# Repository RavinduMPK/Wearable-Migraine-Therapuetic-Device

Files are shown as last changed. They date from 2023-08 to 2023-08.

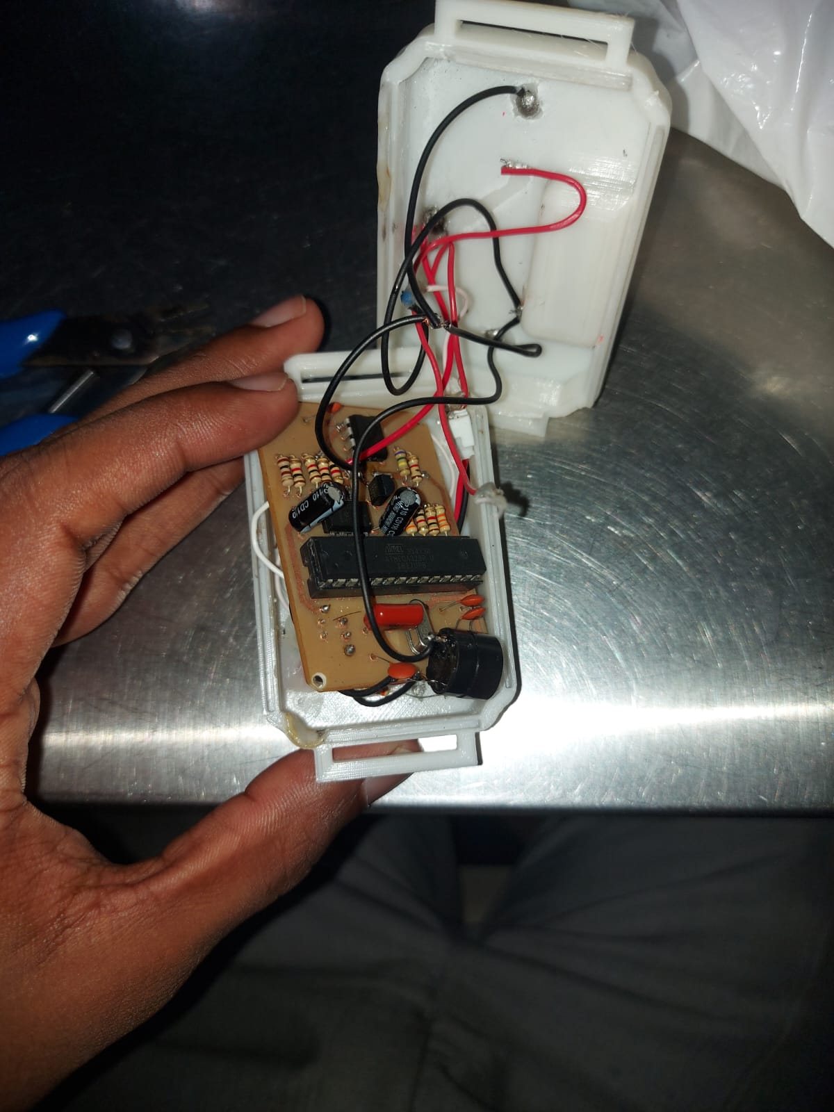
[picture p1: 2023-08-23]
Images/Internal.jpg

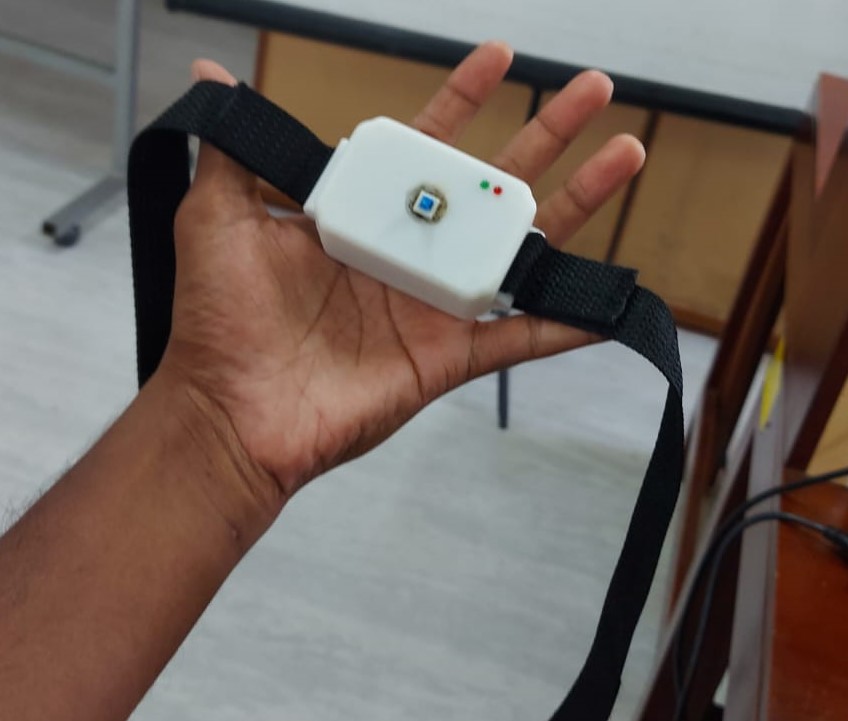
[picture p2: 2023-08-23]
Images/Device view.jpg

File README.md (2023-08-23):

# Wearable Migraine Therapeutic Device
Wear

## Problem

Migraine is a pressing global health issue that lacks a definitive solution. Research surveys have revealed that one out of every ten individuals worldwide experiences the debilitating effects of migraines. This intricate neurological condition manifests with the following characteristics:

- Intense headache localized to one side of the head.
- Moderate to severe throbbing sensation that worsens with movement.


While no permanent medical cure for migraines currently exists, certain methods can alleviate the pain to some extent. Many migraine sufferers resort to massaging their forehead as an external remedy, while others rely on painkillers as a medical treatment. However, these approaches come with limitations:

- Massaging requires interruption of daily activities and is time-consuming.
- Frequent use of painkillers can lead to side effects such as gastritis, ulcers, kidney or liver damage, and more.
These challenges are particularly problematic for students and busy individuals. Given these circumstances, there exists a critical demand for a viable and effective solution to address the issues posed by migraines.

Migraine affects 1 in 10 people globally, causing intense headaches and disruptions. Conventional treatments like painkillers are either time-consuming or carry side effects. An effective and non-invasive solution is needed.


## Solution

Introducing the Wearable Migraine Therapeutic Device – a user-friendly solution that utilizes nerve stimulation to reduce migraine pain. The device offers on-the-go relief, allowing users to continue their activities without interruption.
Device view

### Transcutaneous Electrical Nerve Stimulation (TENS)
Transcutaneous Electrical Nerve Stimulation (TENS) has emerged as a popular non-invasive and self-administered technique for pain relief. This method involves the delivery of a minuscule electrical current through the skin using electrode pads attached to the skin surface. A significant advantage of TENS is its minimal side effects.

The underlying mechanism of TENS is based on the gate control theory of pain. This method effectively reduces the transmission of pain sensation messages to the brain by deactivating relevant sensory fibers. Our approach focuses on alleviating migraine pain by strategically placing electrodes on the forehead. We specifically target the afferent paths of the Supratrochlear and Supraorbital nerves, which belong to the ophthalmic branch of the Trigeminal nerve.

Our method employs high-frequency, low-intensity electrical signals. We begin with low intensity and gradually increase it. This approach is designed to stimulate large diameter, low threshold fibers (A-beta) initially, followed by high threshold fibers (A-delta). This sequential stimulation pattern effectively reduces the transmission of migraine pain sensation messages to the brain, providing relief to patients during migraine episodes.

## Key Features

- **Nerve Stimulation:** Utilizes nerve stimulation to alleviate migraine pain effectively.
- **User-friendly Design:** Lightweight and comfortable for extended wear.
- **Safe and Low Power:** Designed with safety and low power consumption in mind.
- **Gradual Relief:** Provides gradual pain relief during operation.
- **Adjustable:** Equipped with an adjustable band to fit different head sizes.

## Technical Specifications

- **Pulse Frequency:** 100 Hz
- **Pulse Duration:** 500 µs
- **Pulse Width:** 250 µs
- **Step-up Intensity:** 30 µs
- **Max Intensity:** 1 mA
- **Weight:** Approximately 50g

### Electrode Pad
Electrode_pad
- A-Self-adhesive pad
- B-Insulated area
- C-Hook (To hold the electrode pad with the circuit above tightly)

## Architecture

The device's architecture involves a microcontroller, pulse generator, voltage-to-current converter, and feedback outputs. Components work together to generate and deliver the therapeutic effect.



### Inputs
The primary input of the device is facilitated by a push-button switch. For this purpose, we have integrated a 6Pin Two Row Through Hole Mount DPDT Self-Locking Mounting Tact Tactile Power Micro Push Button as our switch.

### Signal Generation Unit
The Signal Generation Unit comprises several sub-modules:

### Micro-controller Unit
This module generates a PWM signal with a varying duty cycle. Our micro-controller programming gradually increases the duty cycle over 16 minutes and then decreases it over the next 4 minutes.



### Digital-Analog Converter
This sub-module converts the PWM signal obtained from the micro-controller into an analog stair-case signal. To achieve this, a second-order filter circuit is employed to accurately filter out harmonics while retaining the DC component of the signal.



### Sampling Signal Generator
A sampling signal, operating at around 100Hz, is required to sample the stair-case signal. To generate this, a 555 timer IC is employed. Given the limitation of the micro-controller in generating such a low-frequency PWM signal, this approach is chosen.



### Sampling Unit
This sub-module samples the stair-case signal. We employ a BJT transistor in switching mode, with calculated resistor values for the base and collector ensuring the transistor operates within the switching region.



### Voltage-Current Converter
In the final stage of the circuit, the generated voltage signal must be converted into a current signal. To achieve this, we've designed an Op-Amp circuit functioning as a voltage-current converter, ensuring the output current remains independent of the output load.



### Outputs
The primary output of our device is the generated current, delivered through three electrode terminals. Additionally, feedback outputs have been integrated to enhance user-friendliness:

A red LED indicates the device is in Power ON mode.
A green LED indicates the device is in Operating mode.
A buzzer emits a beep sound at the beginning and end of the Operating mode.
Power Supply Unit
The device is powered by four coin cells, regulated by a 7805 IC to ensure a stable supply voltage.

## PCB Design

To realize our wearable migraine therapeutic device, a carefully designed Printed Circuit Board (PCB) was a crucial component of the implementation. Our PCB hosts an array of connectors, buttons, microcontrollers, and integrated circuits (ICs) that collectively form the foundation of our device's functionality. The design and layout were facilitated using the Altium software suite.

### Schematic and Layout
The PCB design process began with the creation of a comprehensive schematic diagram. This diagram served as the blueprint for how the various components would connect and interact. Subsequently, the PCB layout was meticulously planned to accommodate the physical placement of components, connectors, and traces.
Schemetic

### Two-Layer PCB Layout
Given the spatial constraints imposed by the device's compact form factor, a two-layer PCB layout was chosen. This design decision enabled us to optimize component placement and routing within the confined dimensions. The careful arrangement of components was essential to ensure effective functionality while minimizing interference and signal degradation.
First PCB

### Assembly
Upon finalizing the design and layout, the PCB was manufactured according to the specifications. Components were then manually soldered onto the PCB, adhering to the designated positions as outlined in the design. Attention to detail during assembly was paramount to ensure reliable connections and the overall integrity of the device.

The PCB design process was a critical step in bringing our wearable migraine therapeutic device to life. It encapsulated both the functional requirements and the constraints imposed by the form factor, resulting in an efficient and compact solution.


#### Note: We designed anoter PCB for this and those files avilable in PCB Design folder.

## Enclosure Design

The design of the enclosure for our wearable migraine therapeutic device was a critical aspect of its overall development. Our enclosure underwent meticulous design and planning to ensure optimal functionality, comfort, and aesthetics. We utilized the SolidWorks design software to bring our vision to life.

### SolidWorks Design Software
For the creation of the enclosure, we leveraged the capabilities of SolidWorks design software. This industry-standard tool enabled us to model and visualize the physical form of the device, making it an essential part of our design process.

### Minimization of Mass
A paramount consideration in the enclosure design was the minimization of mass. By strategically selecting materials and optimizing the enclosure's structure, we aimed to achieve a balance between durability and lightweight design. This emphasis on minimizing mass contributes to the comfort and portability of the device.

### Size Miniaturization
The compact nature of our wearable migraine therapeutic device was a crucial factor in its usability. To this end, we prioritized the miniaturization of the device's size while ensuring that all internal components fit seamlessly within the enclosure. This size optimization enhances the device's wearability and ensures user comfort.

### Multi-Part Enclosure Design
To accommodate the complexity of the device's internal components and maintain a streamlined exterior, we divided the enclosure into three distinct parts. Each part was meticulously designed to seamlessly fit together, providing easy access to internal components while maintaining a cohesive and ergonomic exterior.

Top lid
Bottom lid
Battery case cover

The enclosure design process was a fusion of creativity, functionality, and innovation. Through the utilization of SolidWorks and a dedication to minimizing mass and size, we achieved a multi-part enclosure that embodies both form and function.
Assembled Enclosure

## Testing
Ensuring the correct and reliable operation of our circuit was paramount to the success of our wearable migraine therapeutic device. Rigorous testing procedures were conducted within the laboratory environment to validate the functionality and accuracy of the circuit.

### Waveform Observation and Validation
During the testing phase, we meticulously observed the waveforms at each crucial sub-module of the circuit using an oscilloscope. By doing so, we were able to ensure that the circuit generated the required waveforms accurately at every step of its operation. These observations provided critical insights into the circuit's behavior and helped us verify the functionality of each sub-module.

### Final Output Waveform
The culmination of our testing efforts resulted in the observation of the final output waveform. This waveform represents the desired therapeutic signal that our device generates. Through careful validation, we were able to confirm that the device was successfully generating the necessary waveform, paving the way for its effective use in providing migraine relief.

For a more detailed breakdown of the observed waveforms and their interpretations, we have provided comprehensive documentation under the "Testing" folder, which offers insights into the waveforms' characteristics, trends, and implications.

## User Interface

- **On/Off Button:** Easily switch the device on or off.
- **LED Indicator:** Indicates device status (On/Off, battery level).
- **USB Port:** Rechargeable design for convenience.
- **Beep Speaker:** Auditory feedback for operation status.

## Budget and Cost

- **Components:** Approx. Rs. 13,180
- **Total Cost:** Approx. Rs. 15,000

## Contact

For more information about the Wearable Migraine Therapeutic Device, contact us:

- **Email:** ravindumadushan005@gmail.com

## References

- Burch, Rebecca C., et al. “Migraine.” Neurologic Clinics, vol. 37, no. 4, Nov. 2019.
- "Second Order Filter | Second Order Low Pass Filter Design." Basic Electronics Tutorials, 10 Feb. 2018.

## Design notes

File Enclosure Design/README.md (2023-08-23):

# Enclosure Design
The enclosure design for our wearable migraine therapeutic device was a cornerstone of our product's development. This README offers insights into our enclosure design process, our approach to size optimization, and the tools we utilized.

## SolidWorks Software
For the meticulous creation of our enclosure, we harnessed the capabilities of SolidWorks design software. This industry-standard tool empowered us to model and visualize the physical form of the device, ensuring a high degree of accuracy and precision.


## Size Optimization
One of our paramount considerations was the minimization of the enclosure's size. We undertook rigorous efforts to optimize the dimensions to comfortably fit on the forehead while housing all the necessary components. This size optimization was instrumental in ensuring the device's comfort and wearability.

## Three-Part Enclosure Design
To maintain an optimal balance between functionality and aesthetics, we divided the enclosure into three distinct parts. Each part was thoughtfully designed to fit seamlessly together, allowing for easy access to internal components while presenting a unified and ergonomic exterior.

Top Lid
Bottom Lid
Battery Cover



## 3D Printing and Local Fabrication
With the design solidified, we translated our virtual models into physical reality through 3D printing. Leveraging locally available resources, we materialized our enclosure design into tangible components. This approach facilitated a hands-on experience and allowed us to evaluate the physical enclosure's form and fit.
Device view

## Results
The culmination of our enclosure design efforts resulted in a compact, functional, and aesthetically pleasing housing for our wearable migraine therapeutic device. The utilization of SolidWorks for design and local 3D printing for fabrication enabled us to bring our vision to life and ensure that our device harmoniously integrates technology with user comfort.

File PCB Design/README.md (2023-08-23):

# Designing and Fabricating PCB
The creation of our wearable migraine therapeutic device necessitated the development of a custom Printed Circuit Board (PCB) to accommodate connectors, buttons, microcontrollers, and ICs. This README provides insights into the process of designing, fabricating, and refining our PCB for optimal performance.

## PCB Design Process
To seamlessly integrate our components, we employed the industry-standard software Altium for both PCB schematic design and layout. This approach allowed us to visualize and engineer the intricate connections and layout of our device's internal components.

### Two-Layer PCB Layout
Considering the compact nature of our device, a two-layer PCB layout was chosen. This decision facilitated efficient component placement and effective routing within the confined space, enabling us to optimize the performance while adhering to the spatial constraints.

## Iterative Improvement
### Initial Prototype
For our initial prototype, we designed a simplified PCB and produced it locally. The local manufacturing process allowed us to swiftly iterate on the design while observing the prototype's performance and identifying areas for enhancement.


### Learning from Observations
By meticulously examining the prototype, we identified areas for improvement in terms of component placement, signal integrity, and overall layout. These observations were pivotal in refining our design for enhanced functionality and performance.

### Advanced Iteration
Building on the insights gained from our initial prototype, we iterated on the design to rectify observed errors and incorporate enhancements. Our refined design was meticulously crafted to address previous shortcomings and optimize the circuit layout for improved functionality.



## Collaboration with JLC PCB
To execute our advanced design, we partnered with JLC PCB in China for professional fabrication. This collaboration allowed us to harness their expertise in producing high-quality PCBs at scale, ensuring accuracy and precision in the manufacturing process.

## Results
The culmination of our efforts yielded a refined, professionally fabricated PCB that integrates connectors, buttons, microcontrollers, and ICs seamlessly. The iterative design process, coupled with collaboration with JLC PCB, resulted in a high-performance PCB tailored to our wearable migraine therapeutic device's unique requirements.

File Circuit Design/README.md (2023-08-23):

Schemetic

# Circuit Design
In the creation of our wearable migraine therapeutic device, a meticulously designed circuit played a pivotal role. The circuit encompasses a series of interconnected modules that collectively generate the desired therapeutic output. This README provides an in-depth understanding of each module's function within the circuit design.

## Inputs
The core input of the device is facilitated through a push-button switch. We have chosen the 6Pin Two Row Through Hole Mount DPDT Self-Locking Mounting Tact Tactile Power Micro Push Button as the main switch. This input initiates the device's operation and serves as the catalyst for the subsequent modules.

## Signal Generation Unit
The Signal Generation Unit is a pivotal component, divided into several sub-modules to ensure precision and effectiveness.

### Micro-controller Unit: 
This module is responsible for generating a Pulse Width Modulated (PWM) signal with a dynamically varying duty cycle. Our micro-controller programming orchestrates a gradual increase in the duty cycle over a duration of 16 minutes, followed by a subsequent 4-minute decrease.

### Digital-Analog Converter: 
This sub-module facilitates the conversion of the PWM signal generated by the micro-controller into an analog stair-case signal. To achieve this, a second-order filter circuit is employed, tuned to filter out harmonics and retain the essential DC component of the signal.

### Sampling Signal Generator: 
To sample the stair-case signal from the above sub-module, a 555 timer IC-based signal generator is utilized. The need for a sampling signal around 100Hz necessitated this separate signal generator, as the micro-controller cannot generate such low-frequency PWM signals.

### Sampling Unit: 
This sub-module's primary role is to accurately sample the stair-case signal. It employs a BJT transistor in switching mode, with meticulously calculated base and collector resistor values to ensure the transistor operates within the switching region.

### Voltage-Current Converter: 
In the final phase of the circuit, the generated voltage signal is converted into a current signal. This sub-module employs an Op-Amp circuit functioning as a voltage-current converter. A key feature is its ability to deliver a current signal that remains independent of the output load, ensuring consistent therapeutic output.

## Outputs
The core output of our circuit is the therapeutic current, delivered through three electrode terminals. Furthermore, the device incorporates feedback outputs to enhance user-friendliness:

- A red LED indicates the device is in Power ON mode.
- A green LED indicates the device is in Operating mode.
- A buzzer emits a distinct beep sound at the commencement and conclusion of the Operating mode.

## Power Supply Unit
To sustain the device's operation, four coin cells serve as the primary power source. Additionally, a 7805 IC is utilized to regulate the supply voltage, ensuring consistent and reliable device functionality.

The comprehensive circuit design combines these modules to create a robust and functional wearable migraine therapeutic device. The interconnected modules work in harmony to generate the desired therapeutic effects, enhancing user experience and comfort.

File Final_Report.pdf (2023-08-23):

### University of Moaratuwa Faculty of Engineering Department of Electronic and Telecommunication

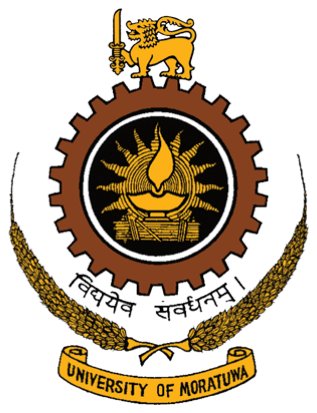
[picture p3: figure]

### BM1190 : Engineering Design Project Group BM-3 SITZU(Migraine theraputic device)

Index No | Name
200381U | Marasinghe M.M.H.N.B.
200400F | Morawaka M.D.
200488E | Pushpakumara H.M.R.M.
200507N | Ranasinghe A.S.N.

## Contents

1 Introduction | 2
2 Product Architecture | 3
3 Design | 7
4 Testing | 11
5 Bill of materials | 12
6 Appendices | 13

1

## 1 Introduction

### 1.1 Problem Description

Migraine is a global health issue without a solution. According to the results of the surveys done, one out of ten people in the world are suffering from migraine. This is a complex neurological disease mainly that results in,

- Intense headache on one side of the head.
- Moderate or sever throbbing sensation getting worse when move.

Although there is no permanent medical treatment for migraine, there are some ways to minimize the pain. Most people who are usually suffering from migraine use to massage their forehead as an external treatment and to take pain killers as a medical treatment. But when the pain occurs, patients have to stop their all-other works to do massaging. It is time consuming and cause big issues to students and busy people. On the other hand, taking pain killers very often can cause side effects such as gastritis, ulcers and kidney or liver damages etc. Therefore, there is a huge need of an effective solution for migraines.

### 1.2 Solution

Transcutaneous electrical nerve stimulation (TENS) is a popular non-invasive self-administered technique to relieve pain. In this method tiny electrical current is delivered through the skin using electrode pads attached to the skin surface. Most importantly this is a technique with few side effects.
The gate control theory of pain is the underlying mechanism behind the TENS. This method reduces the transmission of pain sensation messages to the brain by deactivating the relevant sensory fibers. In our method we placed electrodes on the forehead with intension to minimize the migraine pain. Here we are stimulating the afferent paths of the Supratrochlear and Supraorbital nerves of the ophthalmic branch of the Trigeminal nerve. In our method we are using high frequency low intensity electrical signals. At the beginning low intensity is used and gradually intensity increases. The intension of this is to stimulate selectively large diameter low threshold fibers (A-beta) at first and after that stimulate high threshold (A-delta) fibers. This reduces the transmission of migraine pain sensation messages to the brain and give relief to the patient when migraine is occurred.

2

## 2 Product Architecture

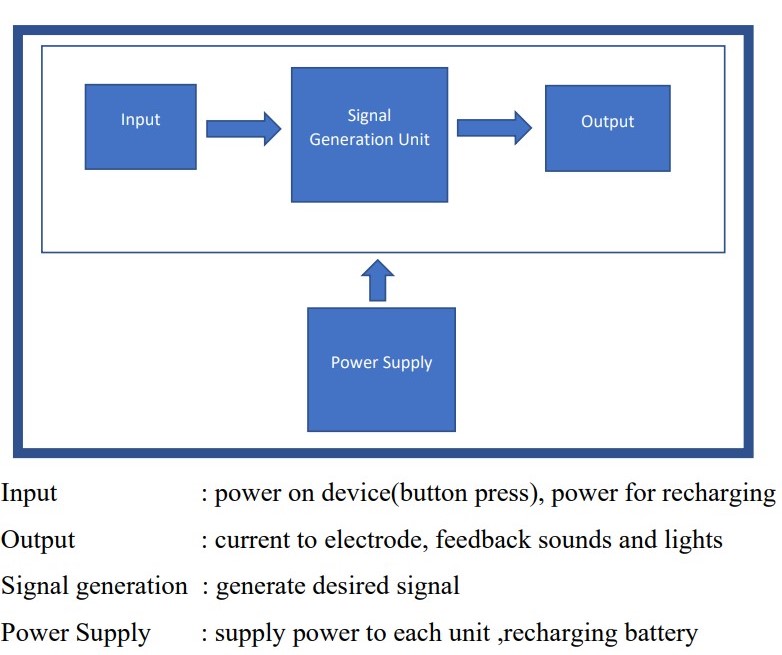
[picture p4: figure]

Figure 1: Product architecture

### 2.1 Main modules

1. Inputs
Push button switch is used as the main input of device.We have used a 6Pin Two Row Through Hole Mount DPDT Self-Locking Mounting Tact Tactile Power Micro Push Button as our switch.
2. Signal Generation Unit
This module has divided into several sub-modules.
- Micro-controller Unit - Generate a PWM signal with varying duty cycle.We have programmed Micro-controller such that it deliver PWM signal with increasing duty cycle for about 16 minutes and then decrease duty cycle for next 4 minutes.

3

- Digital-Analog Converter - This sub-module convert above PWM signal to Analog stair case signal.We have selected cut-off frequency of filter such that filter circuit would filter out all the harmonics except DC component of signal.We have used a second order filter circuit in order to obtain a more accurate output signal.
- Sampling Signal Generator - This signal is used to sample staircase signal obtained in above sub-module.And this unit mainly comprise of 555 timer IC.We could not use a PWM signal obtain from micro-controller for achieve our purpose because we needed sampling signal around 100Hz but micro-controller could not provide such low frequency PWM signal.
- Sampling Unit - Main function of this sub-module is to sample the stair-case signal.For that we used a very primary but efficient method.We used a BJT transistor in switching mode.Base and collector resistor values were calculated to make sure that transistor operates in switching region.
- Voltage-Current Converter In the final stage of our circuit we have to convert generated voltage signal into a current signal.Key feature of this sub-module is it should be able to deliver a current signal independent of output load.So we have used a Op-Amp circuit which functions as a voltage-current converter whose out put current is independent of output load.
3. Outputs
Our main output is the generated current.And it is delivered using 3 electrode terminals.Besides our product has feed-back outputs to make our product user friendly.Two LEDs and a buzzer is used to output feed-backs.A red LED is used to indicate that device is in Power ON mode.A green LED is used to indicate that device is in Operating mode.And buzzers is making beep sound at the beginning and the end of the Operating mode.
4. Power Supply Unit
Four coin-cells are used as main power source of the device.And 7805 IC is used to regulate the supply voltage.

4

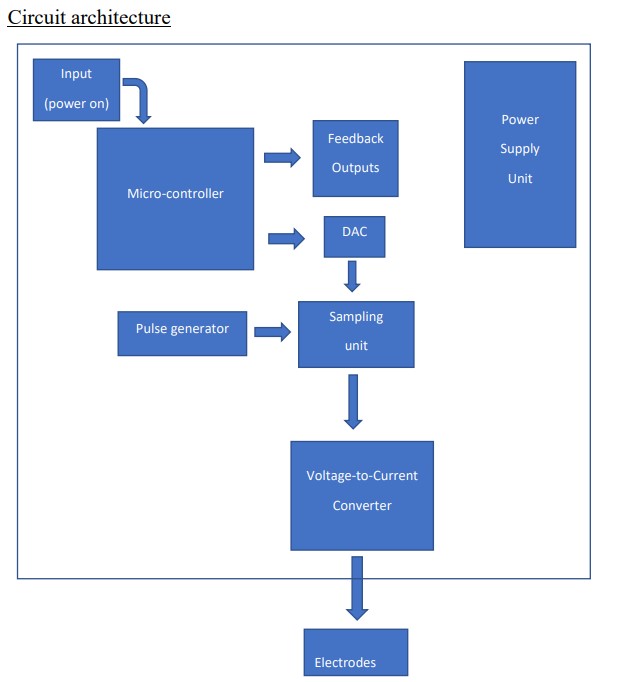
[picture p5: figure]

Figure 2: Circuit architecture

### 2.2 Technical Specification

- Standards

– Pulse frequency :100 Hz

– Pulse duration :500 µs

– Pulse width :250 µs

– Step-up intensity :30 µs

– Intensity : 5 mA

5

- Output Current Waveform - Begins when user switches ON the device and delivers a square pulse current signal with an increasing amplitude for about 16 minutes and decreasing current within about 4 minutes.
- Weight - about 50g
- Dimensions - 7cm x 4.8cm x 3cm (without headband)

### 2.3 Component Specification

- Input Unit
1. 6Pin Two Row Through Hole Mount DPDT Self-Locking Mounting Tact Tactile Power Micro Push Button
- Signal Generation Unit

– Micro-controller Unit

1. Atmega328p
2. 16 MHz oscillator
3. capacitors (22pF x 2)

– DAC Unit

1. LM358 Dual Op-Amp IC
2. Resistors (1kΩ , 33kΩ)
3. capacitors (1µF x 2)

– Sampling Signal Generator

1. NE555 IC
2. resistors (1kΩ , 750kΩ)
3. 10nF capcitor

– Sampling Unit

1. 2N222 transistor
2. resistors (100Ω, 1kΩ)

– Voltage-Current Converter

1. LM358 Dual Op-Amp IC
2. Resistors (1kΩ x 4)
- Output Unit
1. Electrodes
2. 2 LED bulbs
3. 2 resistors
4. 5V buzzer
- Power Supply Unit

6

1. LM7805
2. coin cells
3. Capacitors (100nF x 4)

## 3 Design

### 3.1 Designing circuit

We have designed and simulated our circuit using Proteus software.Initially we started with an analog circuit which can generate square pulse signal with varying amplitude.But as we move on it was converting our design to digital domain was essential.Because we needed to program our device such that it would operate within a fixed time period and vary the amplitude of signal in a manner we specified.

The main modules in our circuit were discussed above.During simulations we have checked out put signal of each stage and verified that signal is generated according to our standards.

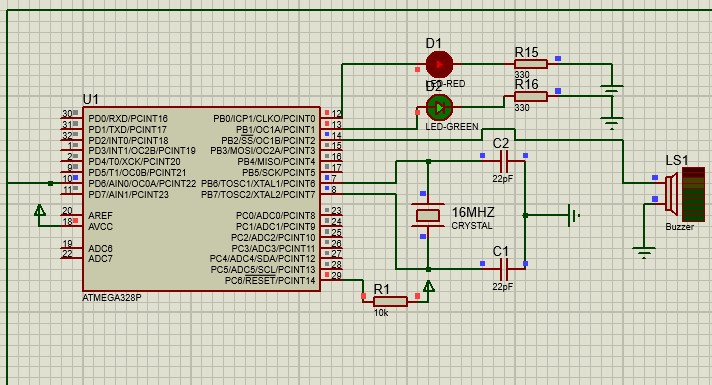
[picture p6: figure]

Figure 3: Micro-controller Unit

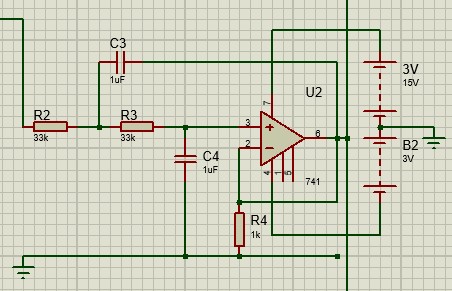
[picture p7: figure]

Figure 4: DAC unit

7

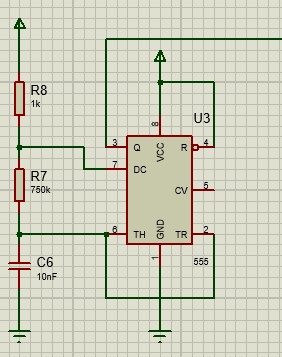
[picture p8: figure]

Figure 5: Sampling Signal Generator Unit

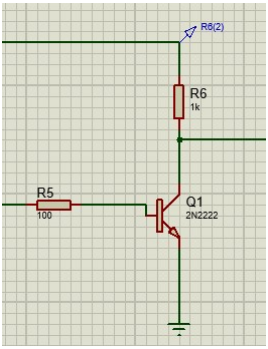
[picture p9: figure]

Figure 6: Sampling Unit

8

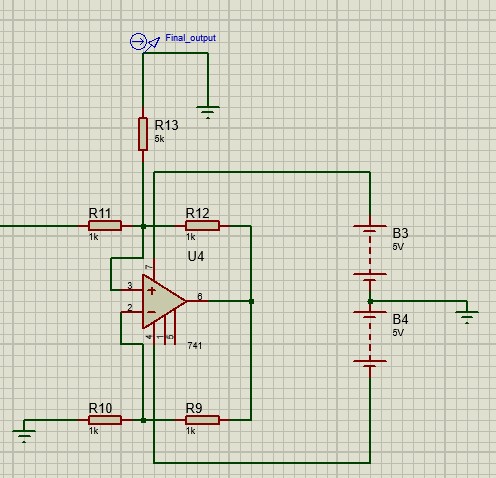
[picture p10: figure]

Figure 7: Voltage-Current Converter

### 3.2 Designing and fabricating PCB

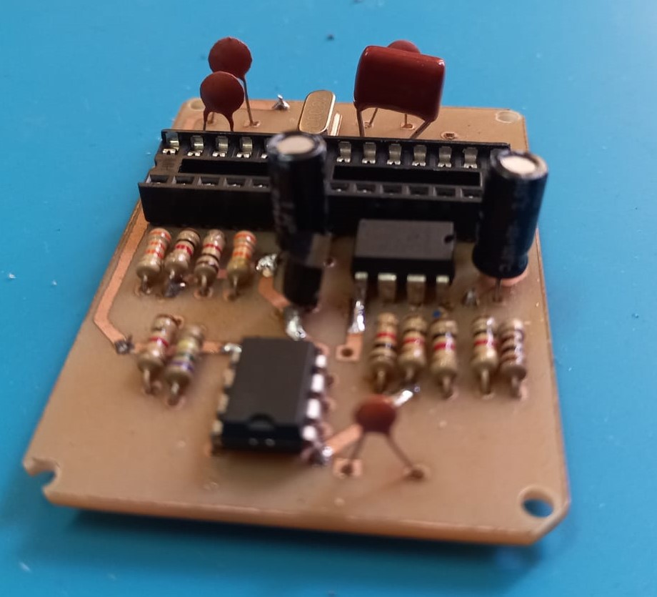
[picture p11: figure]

Figure 8: fabricated PCB

Our product required a Printed Circuit Board with several connectors, buttons, micro controller and ICs. So in order to mount these components on the PCB we used the software Altium to design the PCB schematic and PCB layout.We used two layer PCB layout and after printing PCB, we manually soldiered components.

### 3.3 Enclosure Design

The enclosure design is done using the SolidWorks software.We separated our enclosure into three parts and designed them.

- Top Lid

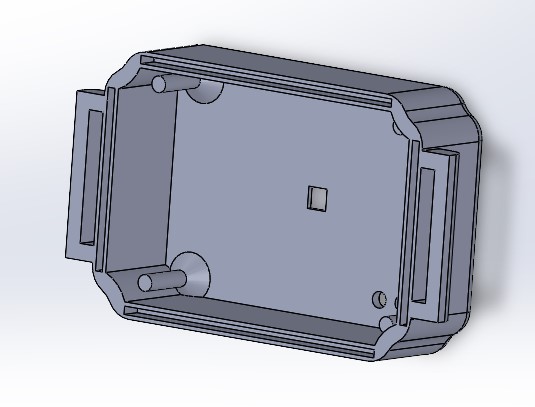
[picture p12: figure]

Figure 9: Top Lid

- Bottom Lid with battery case

9

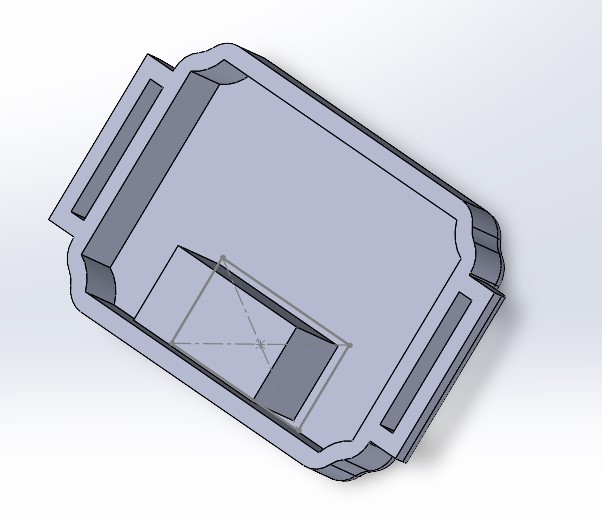
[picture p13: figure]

Figure 10: Bottom Lid

- Battery case cover

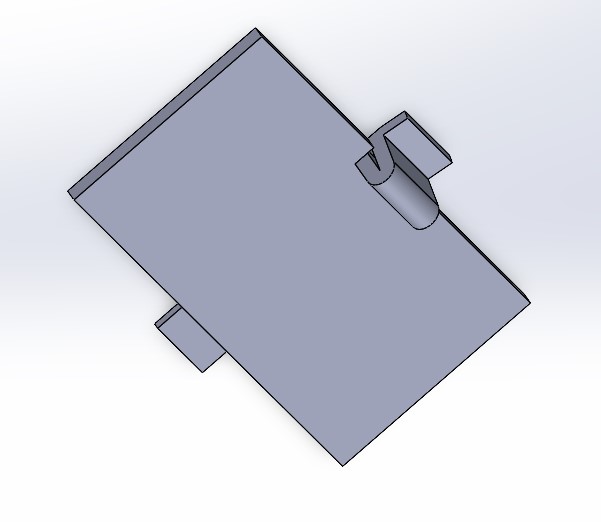
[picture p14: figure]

Figure 11: Battery case cover

After designing parts separately, we assembled them in Solidworks and checked whether they fit together.

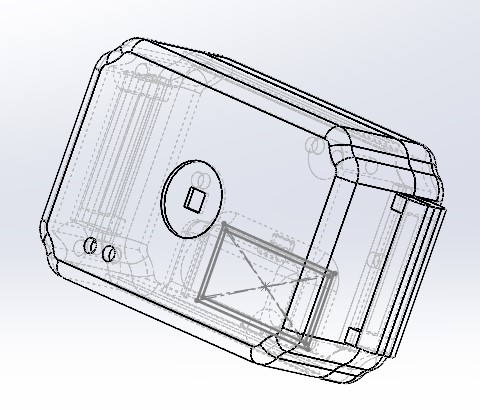
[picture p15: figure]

Figure 12: Assembled Enclosure

10

## 4 Testing

We tested the operation of the circuit at the laboratory to ensure that it works correctly and generates the required wave form. We observed the wave forms at each sub module using the oscilloscope and we were able to get the required wave forms at each step.So the observed final output waveform is as follows.

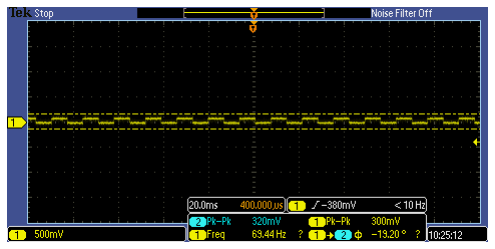
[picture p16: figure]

(a)

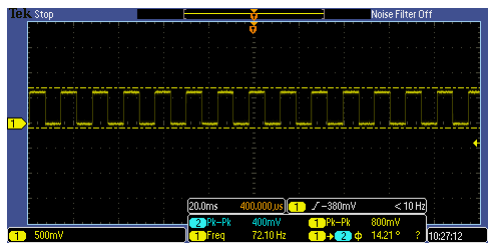
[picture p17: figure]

(b)

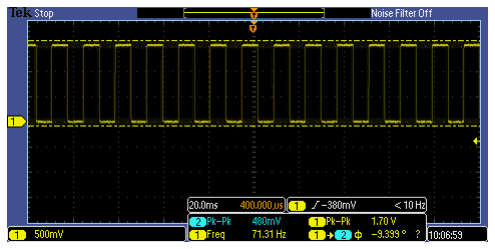
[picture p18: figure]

(c)

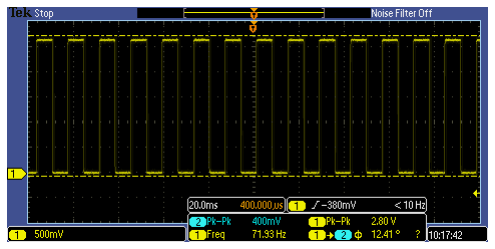
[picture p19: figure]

(d)

(e)

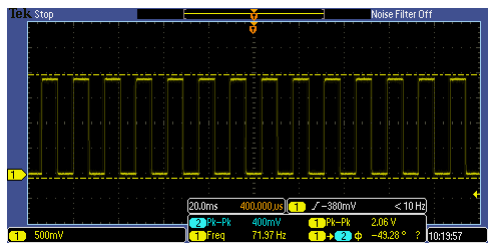
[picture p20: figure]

(f)

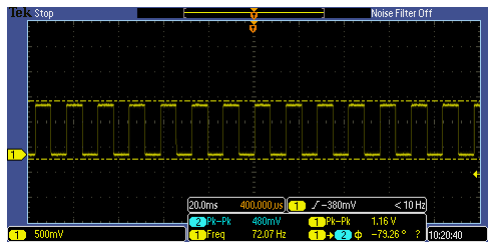
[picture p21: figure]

(g)

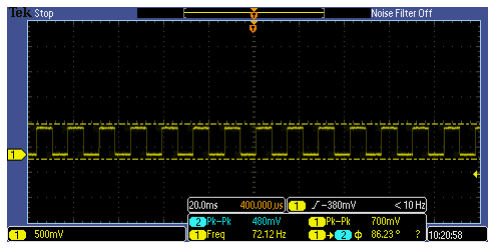
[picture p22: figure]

(h)

11

## 5 Bill of materials

Equipment | Quantity | Net Price (LKR)
Atmega328p | 1 | 1200.00
LM358(dual Op-Amp IC) | 1 | 40.00
555 timer | 1 | 40.00
Resistors | 13 | 26.00
2N2222 transistor | 1 | 5.00
Capacitors | 7 | 50.00
7805 voltage regu-lator | 1 | 40.00
Battery | 4 | 200.00
LED | 2 | 10.00
Button switch | 1 | 20.00
Buzzer | 1 | 80.00
Electrodes | 3 | 300
Other Equipment | | 999.00
PCB | | 500.00
Enclosure | | 1190.00
Cost | | 4400.00
Sales Price | | 10000.00

12

## 6 Appendices

### Appendix I - Circuit Schematic

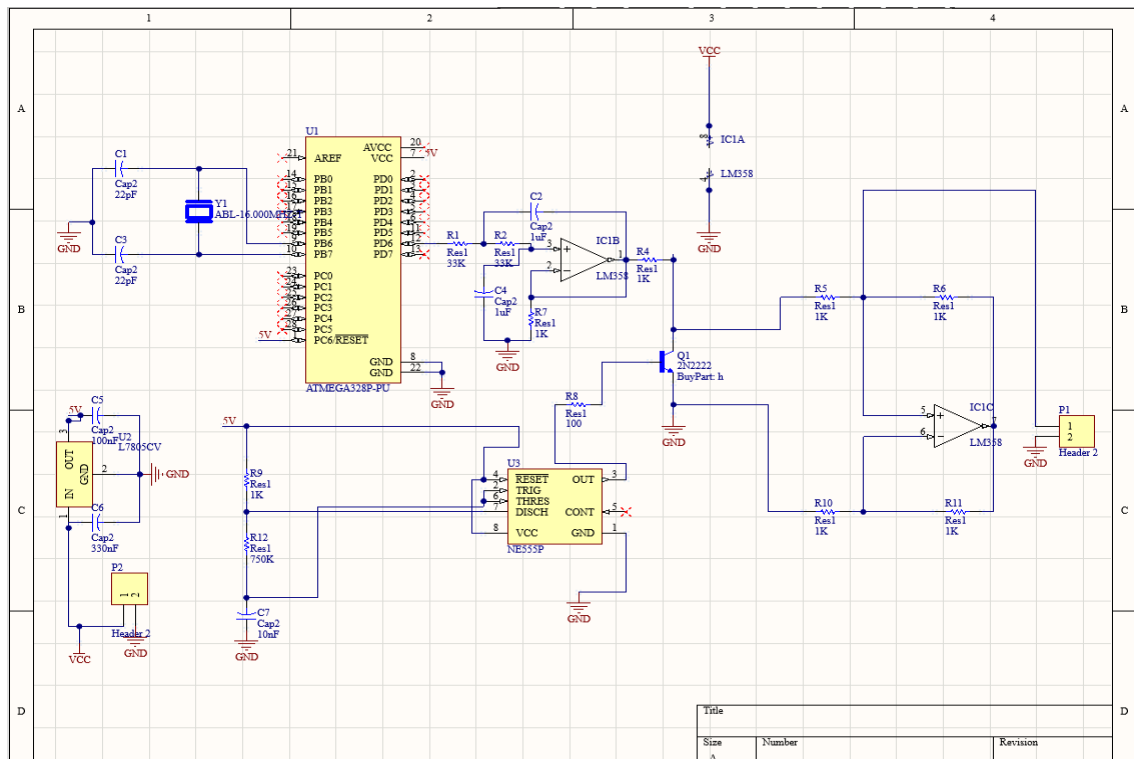
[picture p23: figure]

Figure 13: PCB schematics diagram(drawn using Altium)

13

### Appendix II - PCB design

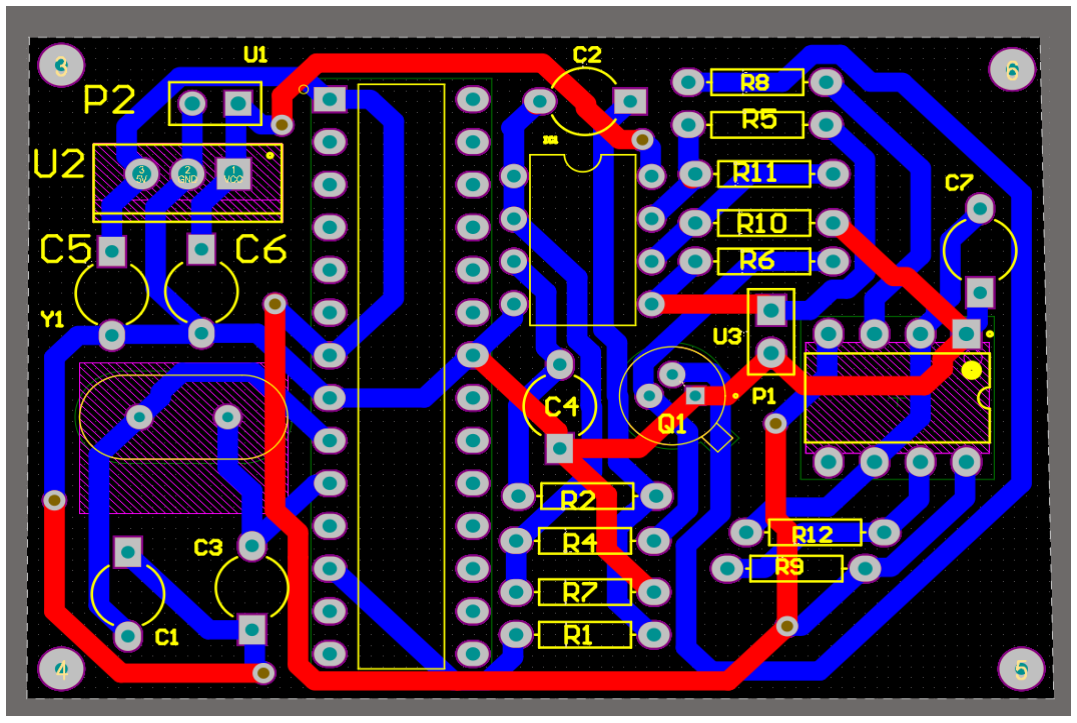
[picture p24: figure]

Figure 14: PCB layout(designed using Altium)

14

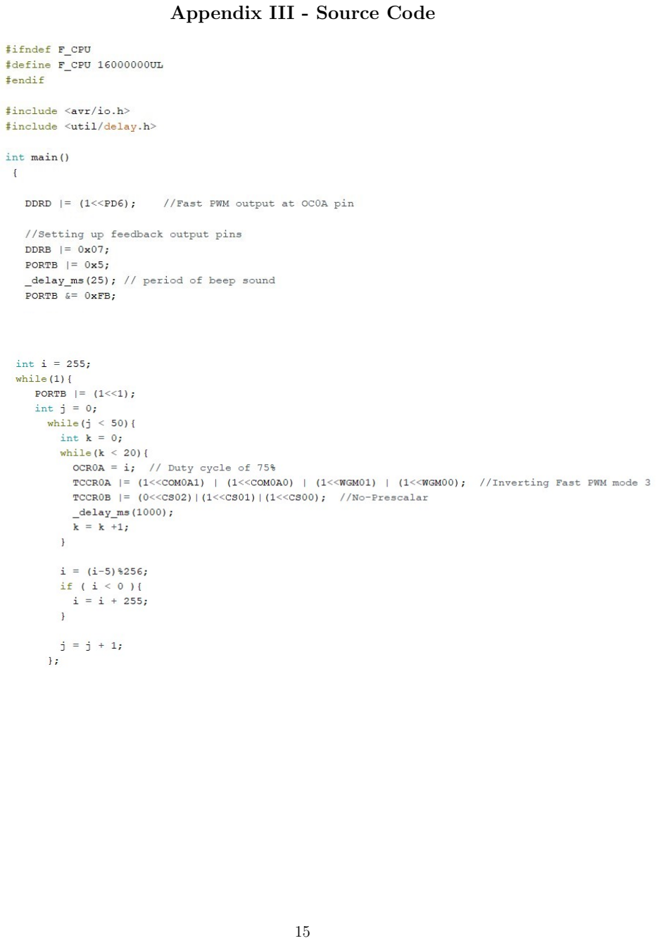
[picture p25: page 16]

### Appendix III - Source Code

15

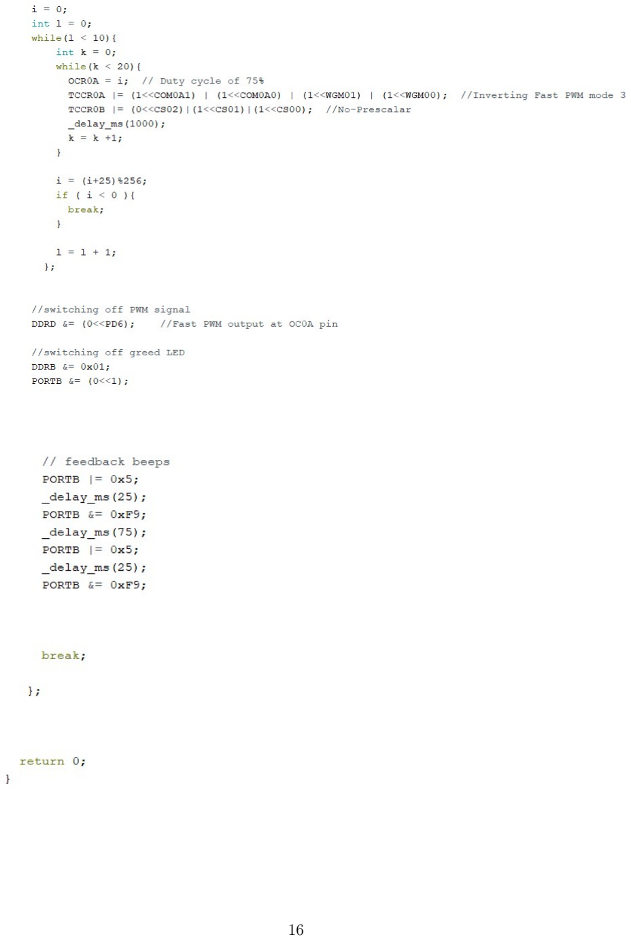
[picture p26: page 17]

16

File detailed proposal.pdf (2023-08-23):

Group Members; MARASINGHE M.M.H.N.B.; MORAWAKA M.D.; 3. PUSHPAKUMARA H.M.R.M. 200488E; RANASINGHA A.S.N.

Engineering project design

❖ Problem:

Migraine is a global health issue without a solution. According to the results of the surveys done, one out of ten people in the world are suffering from migraine. This is a complex neurological disease mainly that results in,

- Intense headache on one side of the head.
- Moderate or sever throbbing sensation getting worse when move.

Although there is no permanent medical treatment for migraine, there are some ways to minimize the pain.

Most people who are usually suffering from migraine use to massage their forehead as an external treatment and to take pain killers as a medical treatment. But when the pain occurs, patients have to stop their all-other works to do massaging. It is time consuming and cause big issues to students and busy people. On the other hand, taking pain killers very often can cause side effects such as gastritis, ulcers and kidney or liver damages etc.

Therefore, there is a huge need of an effective solution for migraines.

❖ Our Solution:

To address this problem, we hope to design a user-friendly wearable migraine therapeutic device. We hope to use a Nerve Stimulation Method for this design. Through our device, we stimulate a nerve that cause migraine and reduce the pain. Therefore, whenever the migraine pain comes patients can wear the device and engage in their work without any disturbances.

❖ Constraints:
- Light weight
- Comfortable
- Safety
- Low power consumption

❖ Technical Feasibility:
For the proper functionality of our device, we need to generate a square pulse wave form with gradually varying amplitude. To meet our goal, we can follow the following procedure.
Step1:
- Program a PWM signal of which duty cycle varies with the time by using an ATmega micro-controller.
Step2:
- Send the generated signal through a digital to analog converter and get the DC output.
Step3:
- Another signal of frequency 100 Hz is generated by 555- timer IC and sample the above signal by sending the two signals via a transistor. Signal generated by 555-timer is set to the base to switch on and off the transistor in a frequency of 100Hz.
Step 4:
- Send the output of the transistor through a voltage to current convertor and the desired current wave form is generated.

All the components needed for our design can be found easily and therefore, our design is technically feasible.

DC Signal

100 Hz signal from 555-timer

Vout

❖ Technical specifications:
- Standards
- Pulse frequency | :100 Hz
- Pulse duration | :500 μs
- Pulse width | :250 μs
- Step-up intensity | :30 μs
- Maximum intensity | :1 mA
- Dimensions

Electrode pad


A-Self-adhesive pad
B-Insulated area
C-Hook (To hold the electrode pad with the circuit above tightly)
- Weight
about 50g

30 mm

❖ Architecture: Product architecture; Signal Generation Unit; Input; Output; Power Supply

Input | : power on device(button press), power for recharging
Output | : current to electrode, feedback sounds and lights

Signal generation : generate desired signal

Power Supply : supply power to each unit ,recharging battery

Circuit architecture; 1)Input; • power on/off • push button; 2)Micro-controller; • Atmega328p (& standalone circuit); Voltage-to-Current; Converter; Micro-controller; DAC; Pulse generator; Sampling; unit; Feedback; Outputs; Electrodes; Power; Supply; Unit; Input; (power on)

- Run main program and generate basic signal (PWM)

3)Power Supply Unit :

- Supply power to each unit
- Batteries, voltage regulator, recharging unit

4)Feedback outputs :

- give feedbacks
- LEDs, buzzer
5)DAC | :
- converts PWM signal to an analog signal
- lowpass filter (OpAmp, 3 resistors, 2 capacitors)

6)Pulse generator :

- generate a pulse signal (which is used for sampling)
- 555timer IC, 2 capacitor, 3 resistors

7)Sampling unit :

- using pulse and analog signal generate final voltage signal
- transistor, 2 resistors

8)V-to-C converter :

- convert final voltage signal to a current signal (which is independent from output resistance)
- OpAmp, 5 resistors

❖ Enclosure:
- On/Off button should be added to switch On or Off the device.
- We are planning make the device rechargeable so that it is more efficient and therefore a USB port was decided to add.
- So, the initial sketch was as follows.

Initial sketches; is On or Off.; are as follows.; Finalized sketches; On/Off button; USB port; Adjustable band; Bulb

- Our device is a wearable device. So, there should be a mechanism to set the device on the forehead. Therefore, we decided to add an adjustable band to hold the device properly on the forehead.
- We further planned to add a bulb to indicate the user whether the device
- So, we did some renovations to the initial sketch and the finalized sketches

❖ UI Design:

- On/ Off button at the front of the device to switch On or Off.
- Small LED bulb just above the On/Off button, to indicate whether the device is On or Off. If the device is in On state, the LED lights up.
- A USB port is there at the bottom of the device to recharge whenever the battery is dead.
- The intensity of the bulb at the front is also an indication about the state of the battery. If the intensity is very low the device should be recharged.
- There is also a beep speaker as feedback to the user to indicate the device is switched on and to indicate the operation is completed.
when switched on | - 1 beep sound
when operation is completed | - 2 beep sounds

❖ Marketing:
- About 26 million in US alone suffer from migraine. Therefore, there is a huge market for a migraine therapeutic device in the world.
- Because of the adjustable band any person can use the device despite the size of head.
- Also, since the device is rechargeable, it can be used again and again and therefore more efficient.
- Our device is designed in such a way that it relieves the pain gradually while operating.
- Any person with any kind of headache can use our device and experience the maximum results.
- Because of the user-friendly design, patient does not need any specific prior knowledge about the device to use.
- Since it is light weight and can properly set to the forehead, the patient does not get any unnecessary stress about holding the device on the head
- The materials used to design the enclosure in contact with the skin are smooth and are guaranteed to have no side effects on the skin such as rashes, itching, reddish skins etc. and therefore, patients find it comfortable to wear.

Marketing will be done mainly via social media like Facebook, Instagram and YouTube. We also can expand our customer base by reaching out to the doctors and informing about the device and its functionality. We further use an official webpage to facilitate our customers to reach us and to aware them about the device.

❖ Sales

When we are designing the product in large scale, we hope to use more effective components while maintaining the device at an affordable price. Also, when producing in large scale, enclosure production can be done in a mold so that it will be cost effective. Our goal is to provide our service to the customers in a cost-effective manner.

❖ Maintenance and repair

We provide our service for customers in case of any failure of the device. In addition, we plan to provide user manual for the users to inform them about how the device should be used and maintained.

❖ Packaging
- The device is packed as a single unit.
- Packaging consists of a cardboard box and the device which is wrapped by a foam sheet is placed securely in the box.
- A user manual will be made available with the product.
- Product name, price, company logo, contact information, weight of the device will be printed on the box.

❖ Disposal

The packaging is made up of eco-friendly disposable materials. We also plan to use an eco-friendly fabric material for the headband. Enclosure and other electronic parts will be recycled. The user manual also includes details about the disposal of the device.

❖ Budget:

Components | Quantity | Unit price (Rs) | Total price (Rs)
ATmega 328p | 1 | 2000 | 2000
NJU77000AF (OpAmps-working with 5V supply) | 2 | 50 | 100
555 timer | 1 | 30 | 30
Resistors | 14 | 10 | 140
2N2222 transistor | 1 | 10 | 10
Capacitors | 5 | 10 | 50
7805 voltage regulator | 1 | 70 | 70
Battery | 2 | 550 | 1100
LED | 2 | 5 | 10
Button switch | 2 | 50 | 100
Beep speaker | 1 | 70 | 70
electrodes | 2 | 1000 | 2000
Enclosure (3D print) | 1 | 5000 | 5000
Enclosure (buttons) | 1 | 500 | 500
headband | 1 | 2000 | 2000
Total | 13180
Approximate Cost | 15000

❖ Task allocation among group members:

Task | Name
Hansa Marasinghe 200381U | Maheesha Morawaka 200400F | Ravindu Pushpakumara 200488E | Sithmini Ranasingha 200507N
Product designing(overall) | 25% | 25% | 25% | 25%
PCB designing | 30% | 20% | 30% | 20%
Enclosure designing | 10% | 25% | 25% | 40%
Safety and Medical concerns | 30% | 40% | 15% | 15%
Documentation | 20% | 20% | 20% | 40%
Budget and financial management | 35% | 20% | 35% | 10%
Testing | 25% | 25% | 25% | 25%

Works Cited

Burch, Rebecca C., et al. “Migraine.” Neurologic Clinics, vol. 37, no. 4, Nov. 2019, pp. 631–649,

10.1016/j.ncl.2019.06.001.

---. “Migraine.” Neurologic Clinics, vol. 37, no. 4, Nov. 2019, pp. 631–649,

10.1016/j.ncl.2019.06.001.

“Second Order Filter | Second Order Low Pass Filter Design.” Basic Electronics Tutorials, 10 Feb.

2018, www.electronics-tutorials.ws/filter/second-order-filters.html.

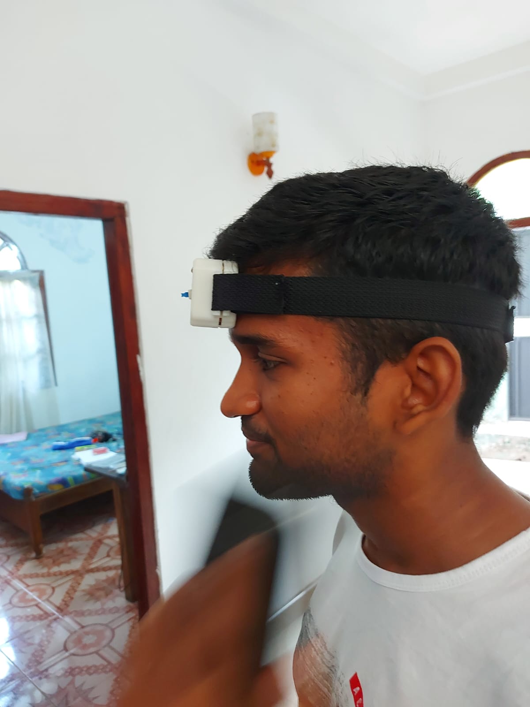
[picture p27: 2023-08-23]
Images/Side look.jpg

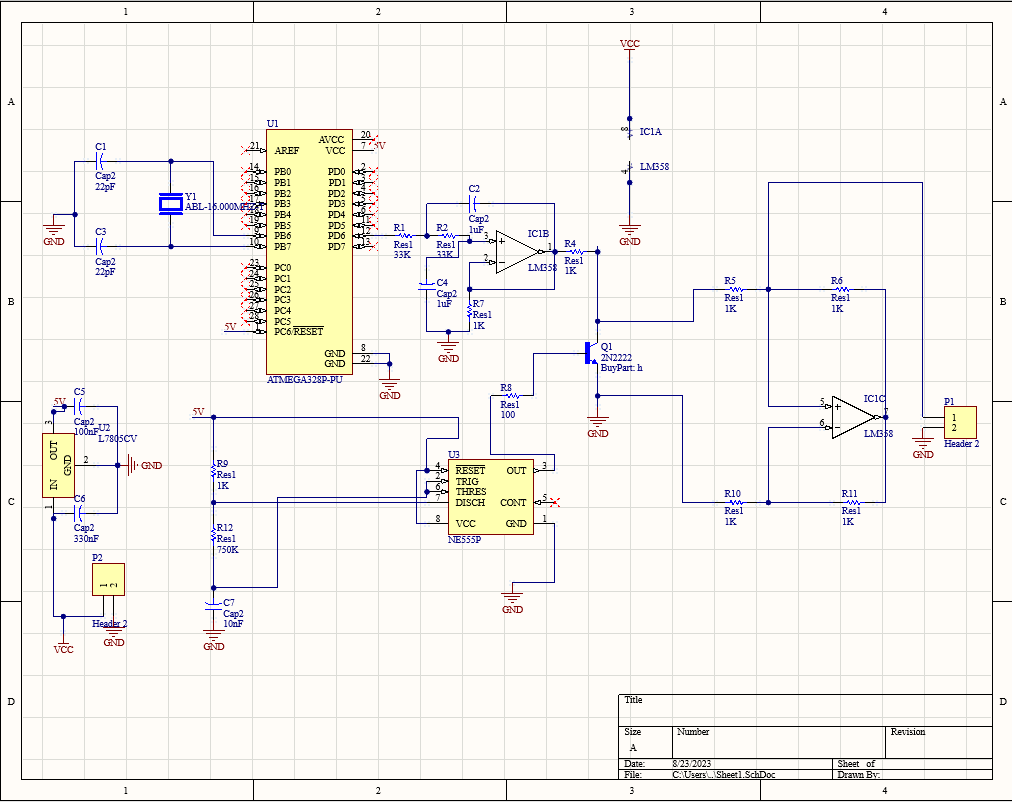
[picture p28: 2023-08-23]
Images/Schemetic.png

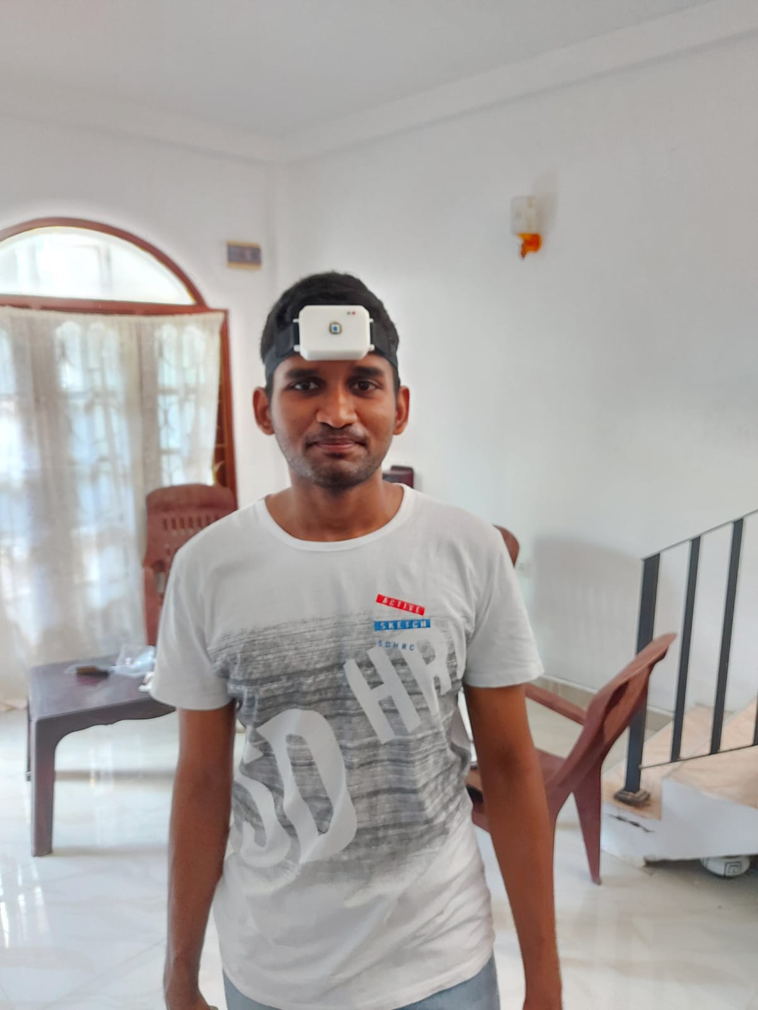
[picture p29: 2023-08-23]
Images/Front look.jpg

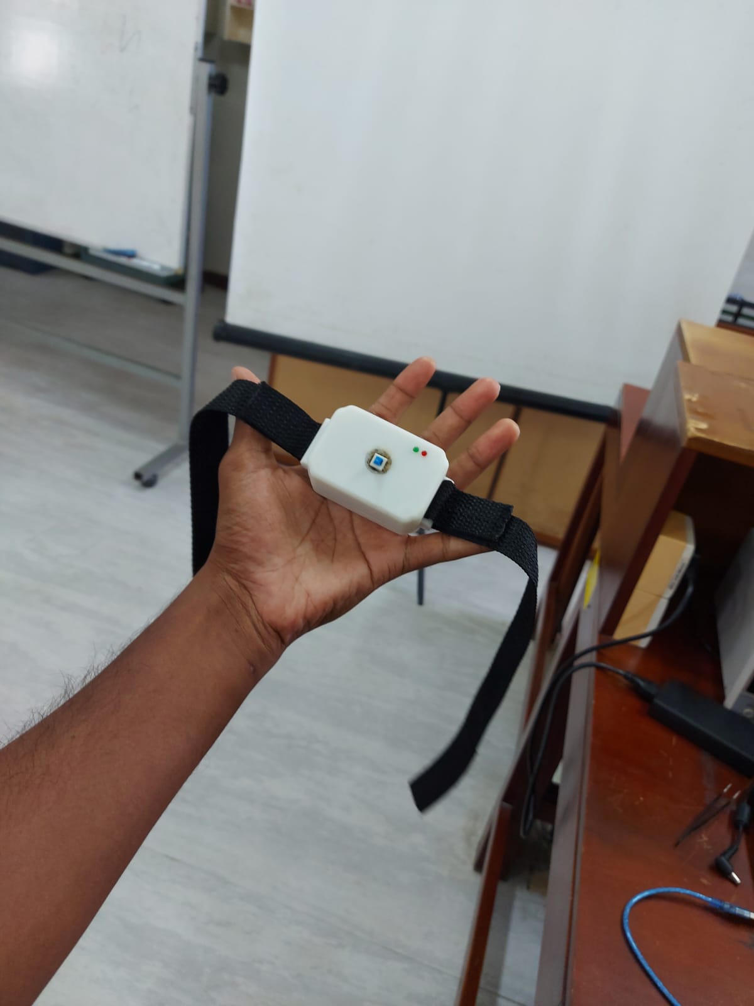
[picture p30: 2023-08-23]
Images/Device.jpg

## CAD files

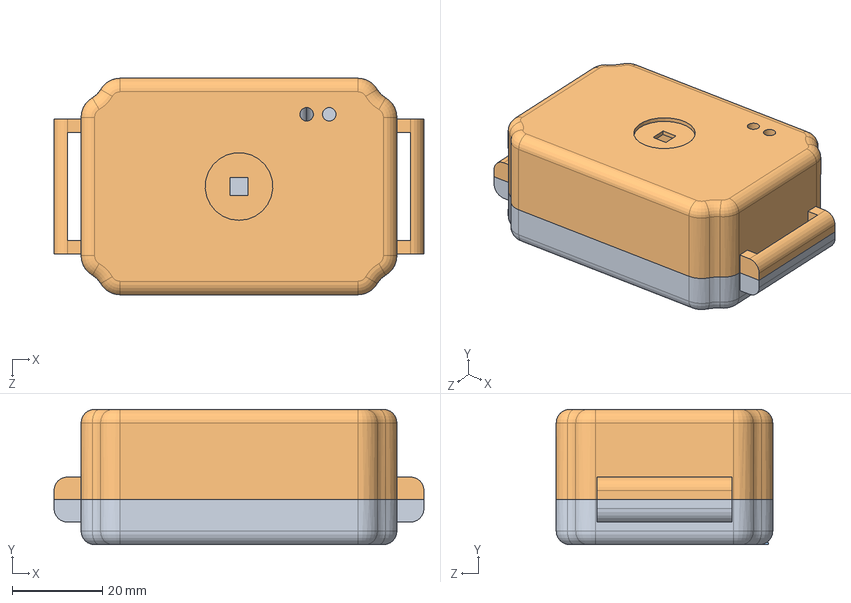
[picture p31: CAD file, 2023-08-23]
Enclosure Design/Assembled Enclosure.SLDASM
82.0 x 30.0 x 48.0 mm
bottom with battery final
up lid final
batteryLid

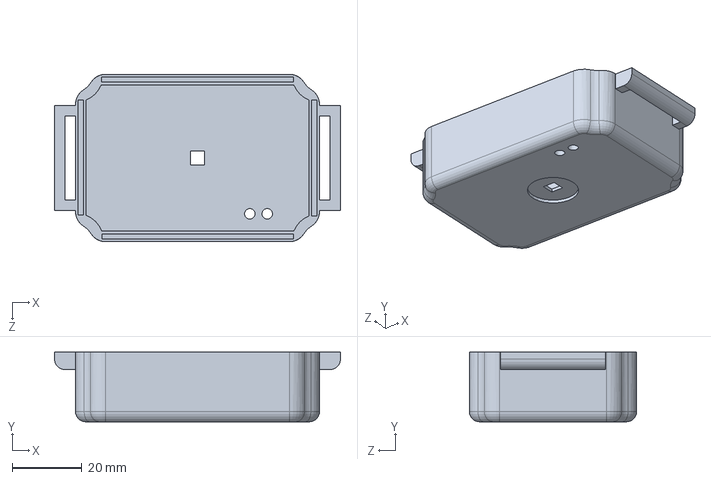
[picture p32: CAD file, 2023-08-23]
Enclosure Design/up lid final .SLDPRT
82.0 x 20.0 x 48.0 mm

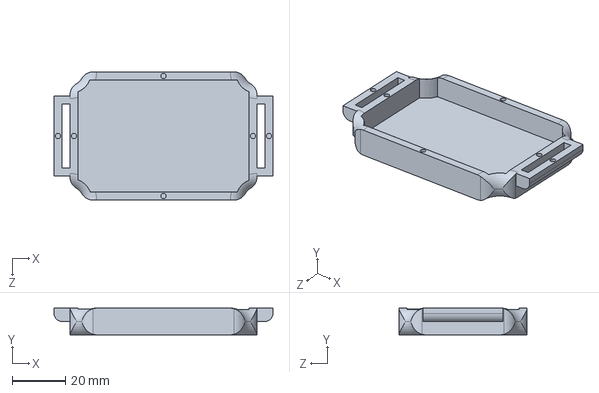
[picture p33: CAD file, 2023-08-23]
Enclosure Design/up lid.SLDPRT
82.0 x 10.0 x 48.0 mm

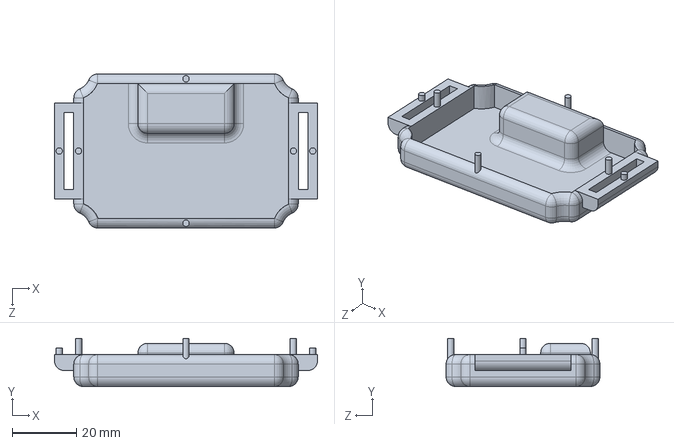
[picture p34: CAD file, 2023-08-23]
Enclosure Design/bottom with battery holder.SLDPRT
82.0 x 15.0 x 48.0 mm

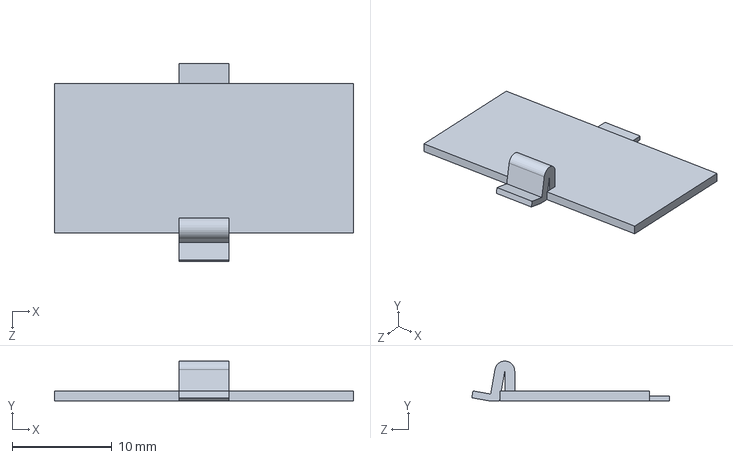
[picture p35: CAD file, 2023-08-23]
Enclosure Design/batteryLid.SLDPRT
30.0 x 4.00 x 19.8 mm

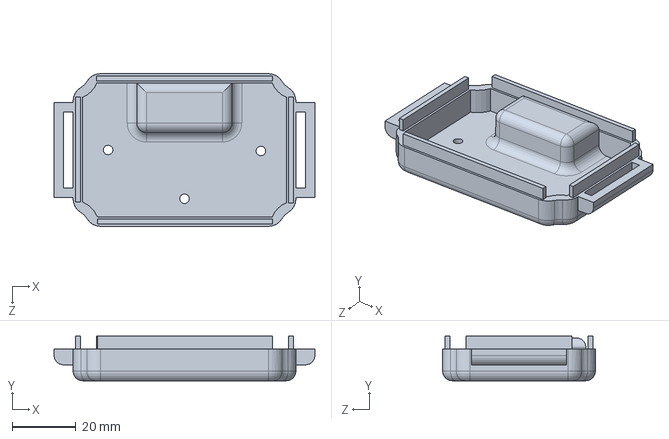
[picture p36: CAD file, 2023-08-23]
Enclosure Design/bottom with battery final.SLDPRT
82.0 x 14.0 x 48.0 mm

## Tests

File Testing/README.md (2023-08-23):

# Testing
Ensuring the precision and reliability of our circuit's operation was a pivotal aspect of our project's success. Rigorous testing procedures were carried out within a controlled laboratory environment to validate the functionality and accuracy of our circuit design.

## Oscilloscope Observations
To comprehensively assess the performance of our circuit, we employed an oscilloscope to visualize and analyze waveforms at each crucial sub-module. By directly observing the waveforms, we verified that the circuit was generating the required waveforms as per our design specifications. This meticulous observation allowed us to ensure the correct operation of the circuit and validate the functionality of each individual sub-module.

## Verified Final Output Waveform
Through the collective observations and analyses at each sub-module, we confidently observed and documented the final output waveform. This waveform serves as a tangible representation of the device's therapeutic signal generation. Its accuracy and consistency were critical in affirming that the circuit successfully met our intended objectives.

Our commitment to rigorous testing and waveform observation validated the precision of our circuit's operation, ensuring that it reliably generates the required waveforms to provide effective migraine relief.

You can find step-by-step test results here. (Behavior of the waveform from step 1 - step 8)

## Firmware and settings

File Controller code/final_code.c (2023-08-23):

#ifndef F_CPU
#define F_CPU 16000000UL
#endif

#include <avr/io.h>
#include<util/delay.h>

int main()
{
  DDRD |= (1 << PD6); //Fast PWM output at OC0A pin

  //Setting up feedback output pins
  DDRB |= 0x07;
  PORTB |= 0X5;
  _delay_ms(25); //period of beep sound
  PORTB &= 0xFB;

  int i = 255;
  while(1){
    PORTB |= (1<<1);
    int j = 0;
    while (j < 50){
      int k = 0;
      while (k < 20){
        OCR0A = i; // Duty cycle of 75%
        TCCR0A |= (1<<COM0A1) | (1<<COM0A0) | (1<<WGM01); //Inverting Fast PWM mode 3
        TCCR0B |= (0<<CS02) | (1<<CS01) | (1<<CS00); // No-Prescalar
        _delay_ms(1000);
        k = k+1;
      }

      i = (i-5) % 256;
      if (i < 0){
        i = i + 255;
      }

      j = j + 1;
    };

    i = 0;
    int l = 0;
    while(l < 10){
      int k = 0;
      while(k < 20){
        OCR0A = i; //Duty cycle of 75%
        TCCR0A |= (1<<COM0A1) | (1<<COM0A0) | (1<<WGM01); //Inverting Fast PWM mode 3
        TCCR0B |= (0<<CS02) | (1<<CS01) | (1<<CS00); // No-Prescalar
        _delay_ms(1000);
        k = k + 1;
      }

      i = (i+25)%256;
      if (i < 0){
        break;
      }

      l = l + 1;
    };

    // Switching off PWM signal
    DDRD &= (0<<PD6); //Fast PWM output at OC0A pin

    //switching off greed LED
    DDRB &= 0x01;
    PORTB &= (0<<1);

    //feedback beeps
    PORTB |= 0x5;
    _delay_ms(25);
    PORTB &= 0xF9;
    _delay_ms(75);
    PORTB |= 0x5;
    _delay_ms(25);
    PORTB &= 0xF9;

    break;
  };

  return 0;
}

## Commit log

2023-08-23 Circuit design
2023-08-23 First PCB
    [PCB1.PcbDoc]
2023-08-23 Second PCB
    [PCB2.PcbDoc]
